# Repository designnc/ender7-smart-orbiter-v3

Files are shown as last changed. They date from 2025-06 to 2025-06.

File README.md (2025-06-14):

# Creality Ender 7 - Smart Orbiter 3 + Klipper Build

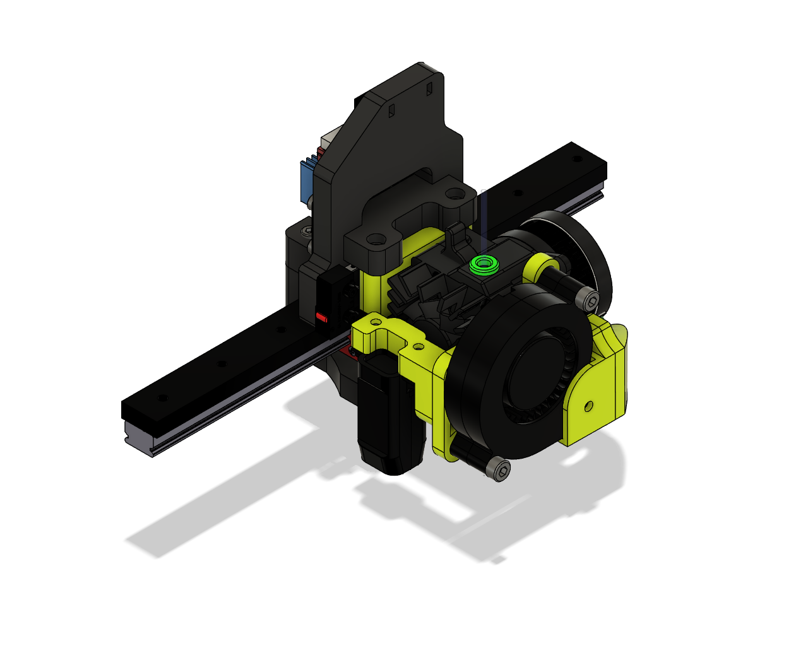
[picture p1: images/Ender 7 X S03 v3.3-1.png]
Overview Image


## Table of Contents / Tabla de Contenidos

- [Project Description / Descripción del Proyecto](#project-description--descripción-del-proyecto)
- [Important Warnings / Advertencias](#important-warnings--advertencias)
- [Repository Structure / Estructura del Repositorio](#repository-structure--estructura-del-repositorio)
- [Klipper Configuration / Configuración de Klipper](#klipper-configuration--configuración-de-klipper)
- [Mount Files / Archivos de Montaje](#mount-files--archivos-de-montaje)
  - [Assembly Notes / Notas de Ensamblaje](#assembly-notes--notas-de-ensamblaje)
- [EzMount Mod / Mod EzMount](#ezmount-mod--mod-ezmount)
- [Known Issues / Problemas Conocidos](#known-issues--problemas-conocidos)
- [Installation / Instalación](#installation--instalación)
- [Credits / Créditos](#credits--créditos)
- [License / Licencia](#license--licencia)

---

## Project Description / Descripción del Proyecto

This project documents the modification of a **Creality Ender 7** 3D printer using a **Smart Orbiter 3** direct-drive extruder, combined with **Klipper** firmware. The goal is to improve print quality, extrusion accuracy, and compatibility with flexible filaments.

Este proyecto documenta la modificación de una **Creality Ender 7** con un extrusor directo **Smart Orbiter 3**, utilizando firmware **Klipper**, con el fin de mejorar la calidad de impresión y la compatibilidad con filamentos flexibles.

🔗 Learn more / Más información: [https://www.orbiterprojects.com/so3/](https://www.orbiterprojects.com/so3/)

---

## Important Warnings / Advertencias

1. **Reduced print volume / Área de impresión reducida**:  
   From / De **250x250x300 mm** → To / A **240x240x295 mm**

2. **belt modification / Modificación de correas**:  
   You'll need to trim the belts / Se deben recortar ligeramente las correas.

3. **Y endstop relocation / Reubicación del endstop del eje Y**:  
   Must be moved forward / Debe moverse hacia adelante.  
   ✅ Adapter included / Adaptador incluido

---

## Repository Structure / Estructura del Repositorio

- `mount/3mf/`: Printable `.3mf` files / Archivos `.3mf` listos para imprimir  
- `mount/editable/`: Editable `.step` files / Archivos `.step` editables  
- `mount/Ender 7 X SO3 v.3.3/`: Main mount  
- `klipper/`: Klipper config / Configuración Klipper  
- `slicer/OrcaSlicer/`: OrcaSlicer profiles  
- `images/`: Assembly photos / Fotos del ensamblaje  
- `wiring/`: Wiring diagrams / Diagramas de conexiones  
- `SO3/SO3_EzMount_v1/`: Fan + probe mount mod

---

## Klipper Configuration / Configuración de Klipper

- `printer.cfg`: Main config  
- `SO3.cfg`: Smart Orbiter 3 config  
- `crtouch.cfg` / `microprobe.cfg`: Probes  
- `drivers_tmc2209.cfg` / `tmc5160.cfg`: Stepper drivers  
- `macros.cfg`: Useful macros

Modular configuration using `include`.

---

## Mount Files / Archivos de Montaje

Parts to mount the Smart Orbiter 3 on the Ender 7:

- `3mf/`: Ready-to-print  
- `editable/`: Editable `.step` for customization  
- Main mount: `mount/Ender 7 X SO3 v.3.3/`

### Assembly Notes / Notas de Ensamblaje

The main mount located in `mount/Ender 7 X SO3 v.3.3/` includes all components required to attach the Smart Orbiter 3 to the Ender 7.

- Uses **M3 screws** and **heat-set threaded brass inserts**
- Includes motor mount, hotend support, fan duct, and belt holder
- Exact screw lengths and quantities to be confirmed

---

El montaje principal ubicado en `mount/Ender 7 X SO3 v.3.3/` incluye todas las piezas necesarias para instalar el Smart Orbiter 3 en la Ender 7.

- Utiliza **tornillos M3** y **insertos metálicos tipo termofijado**
- Incluye soporte de motor, soporte de hotend, ducto de ventilación y tensor de correa
- Las longitudes y cantidades exactas de tornillos serán confirmadas

---

## EzMount Mod / Mod EzMount

Custom mount for the fan and probe directly on SO3:

- Located in `SO3/SO3_EzMount_v1/`
- `.3mf` files
- Previews:

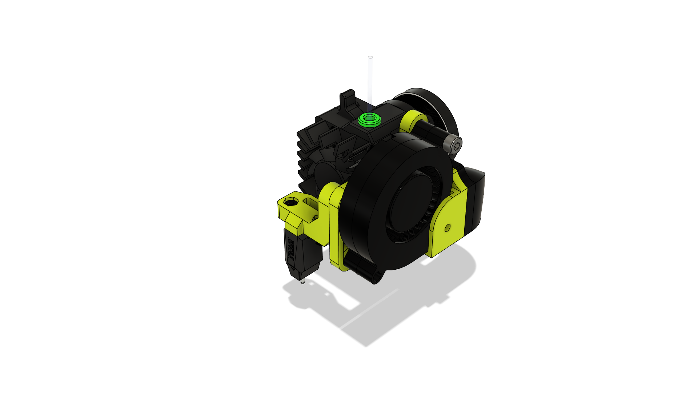
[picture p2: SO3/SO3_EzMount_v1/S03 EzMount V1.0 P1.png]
S03 EzMount P1
  
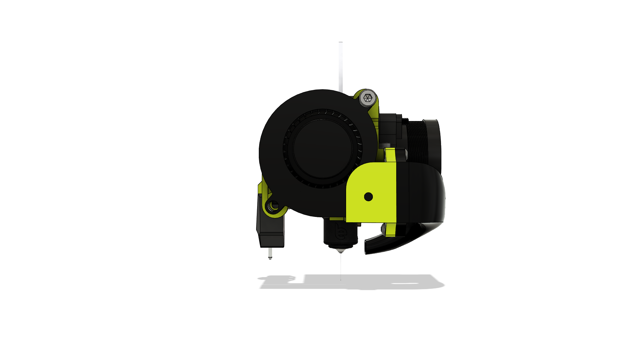
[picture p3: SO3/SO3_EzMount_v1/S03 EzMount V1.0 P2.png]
S03 EzMount P2
  
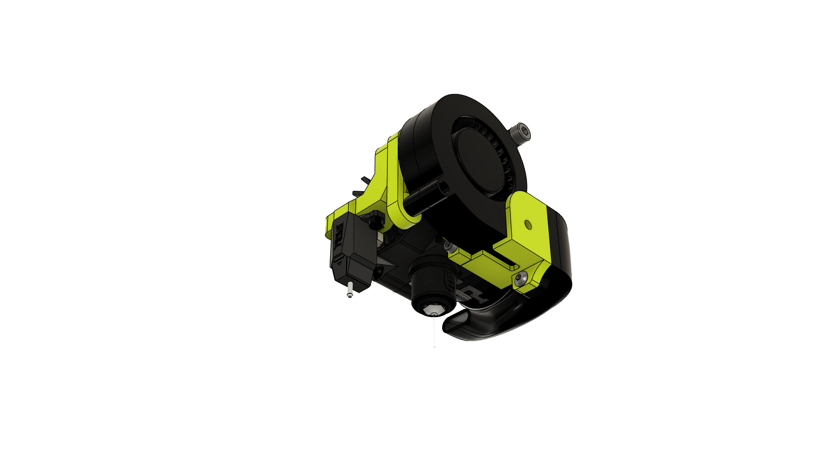
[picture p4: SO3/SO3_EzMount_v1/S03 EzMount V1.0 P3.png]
S03 EzMount P3


> This mod simplifies wiring and reduces the number of printed parts.

---

## Known Issues / Problemas Conocidos

These issues may vary depending on print speed, slicer settings, and printer condition.

---

Estos problemas pueden variar según la velocidad de impresión, el laminador y el estado de la impresora.

### 🌀 Vibrations / Vibraciones

- Some noticeable **vibrations** during fast movements or high-speed printing  
- Using the original **plastic cover** over the head may worsen this — removal is recommended

---

Durante movimientos rápidos o impresiones a alta velocidad, se pueden notar **vibraciones**.  
El uso de la **tapa protectora plástica original** puede aumentar estas vibraciones — se recomienda retirarla.

### 🔊 Fan Noise / Ruido del Ventilador

- The small **cooling fan on the SO3** can produce a **high-pitched noise** ("mosquito-like") due to its speed and size

---

El pequeño **ventilador de enfriamiento del SO3** puede generar un **ruido agudo tipo mosquito** debido a su alta velocidad y tamaño reducido.

---

## Installation / Instalación

1. Print parts from `mount/3mf/` or `SO3_EzMount_v1/`  
2. Trim Y belts and relocate endstop (adapter included)  
3. Load Klipper config files from `klipper/`  
4. Tune PID, axis offsets and travel limits  
5. Import OrcaSlicer profile from `slicer/OrcaSlicer/` *(coming soon)*

---

## Credits / Créditos

Based on: **Smart Orbiter 3** by **Dr. Róbert Lőrincz**, manufactured in collaboration with **LDO Motors**  
Mod design and adaptation for Ender 7 by **@designnc**  
Thanks to / Gracias a: Klipper + Ender 7 community

---

## License / Licencia

This project is licensed under the **Creative Commons Attribution-NonCommercial-ShareAlike 4.0 International (CC BY-NC-SA 4.0)** license.

You are free to remix, adapt, and build upon this work **non-commercially**, as long as you **credit the original author** (@designnc) and **license your new creations under identical terms**.

More info: [https://creativecommons.org/licenses/by-nc-sa/4.0/](https://creativecommons.org/licenses/by-nc-sa/4.0/)

---

Este proyecto está licenciado bajo **Creative Commons Atribución-NoComercial-CompartirIgual 4.0 Internacional (CC BY-NC-SA 4.0)**.

Puedes modificar, adaptar y crear versiones derivadas **solo para uso no comercial**, siempre que **des crédito al autor original** (@designnc) y **compartas tus nuevas versiones bajo la misma licencia**.

Más información: [https://creativecommons.org/licenses/by-nc-sa/4.0/deed.es](https://creativecommons.org/licenses/by-nc-sa/4.0/deed.es)

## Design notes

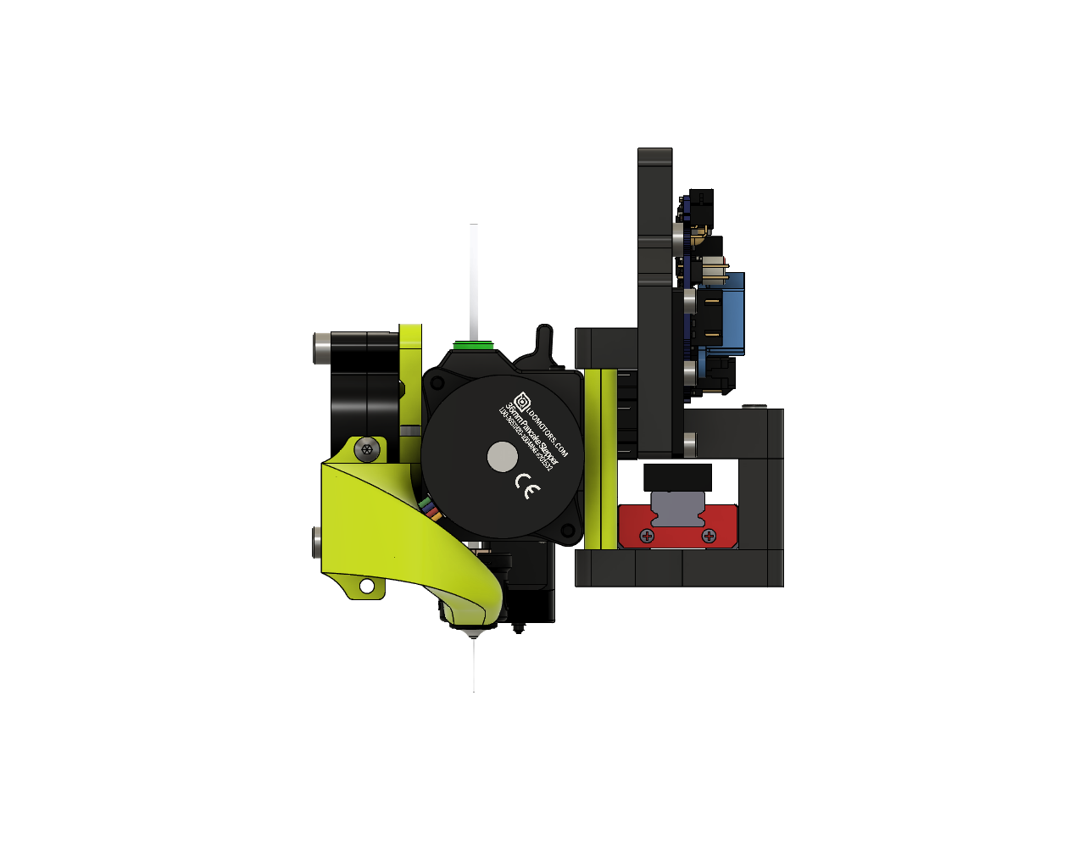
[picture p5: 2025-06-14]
images/Ender 7 X S03 v3.3-right.png

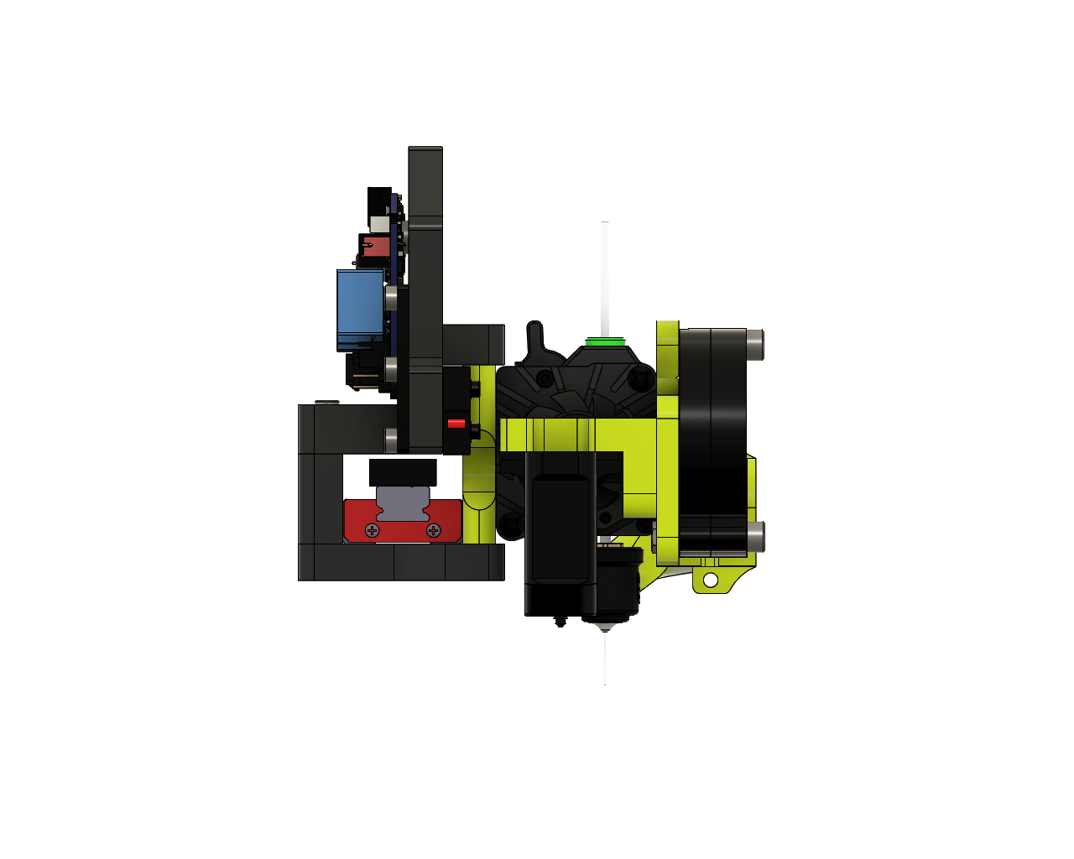
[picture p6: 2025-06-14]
images/Ender 7 X S03 v3.3-left.png

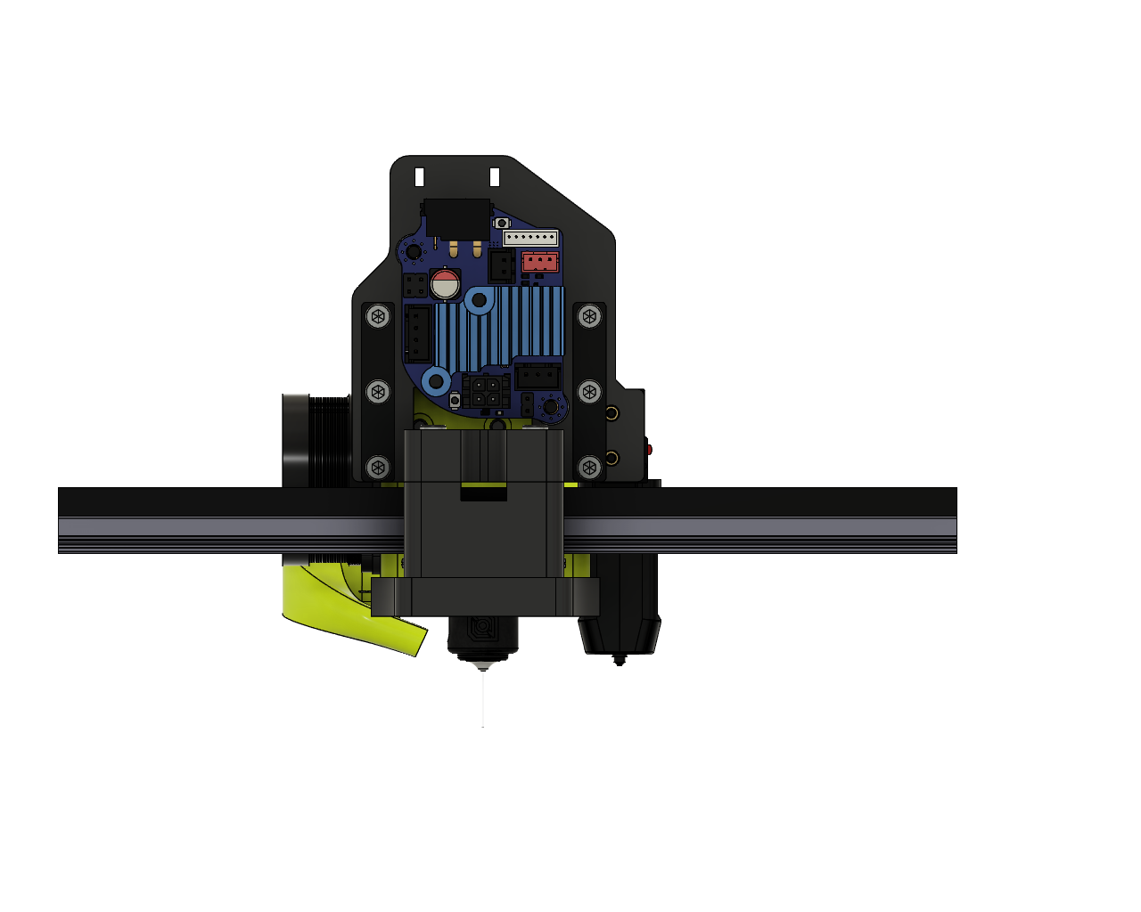
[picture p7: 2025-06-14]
images/Ender 7 X S03 v3.3-back.png

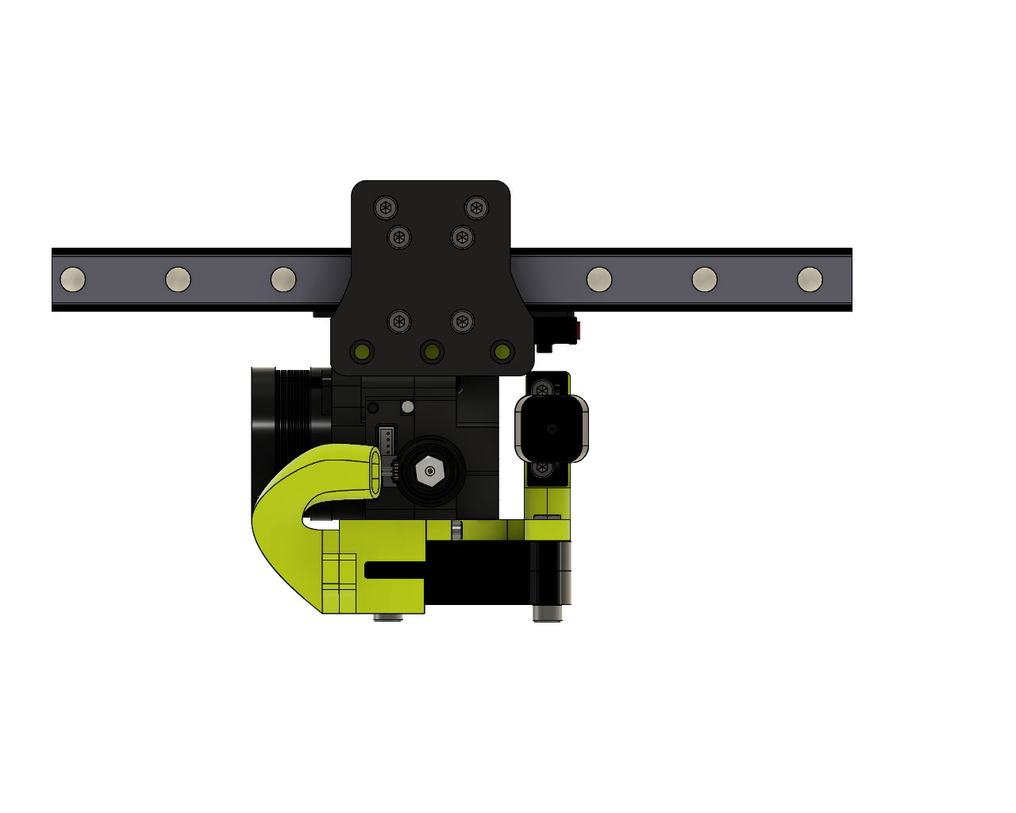
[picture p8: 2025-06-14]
images/Ender 7 X S03 v3.3-bottom.png

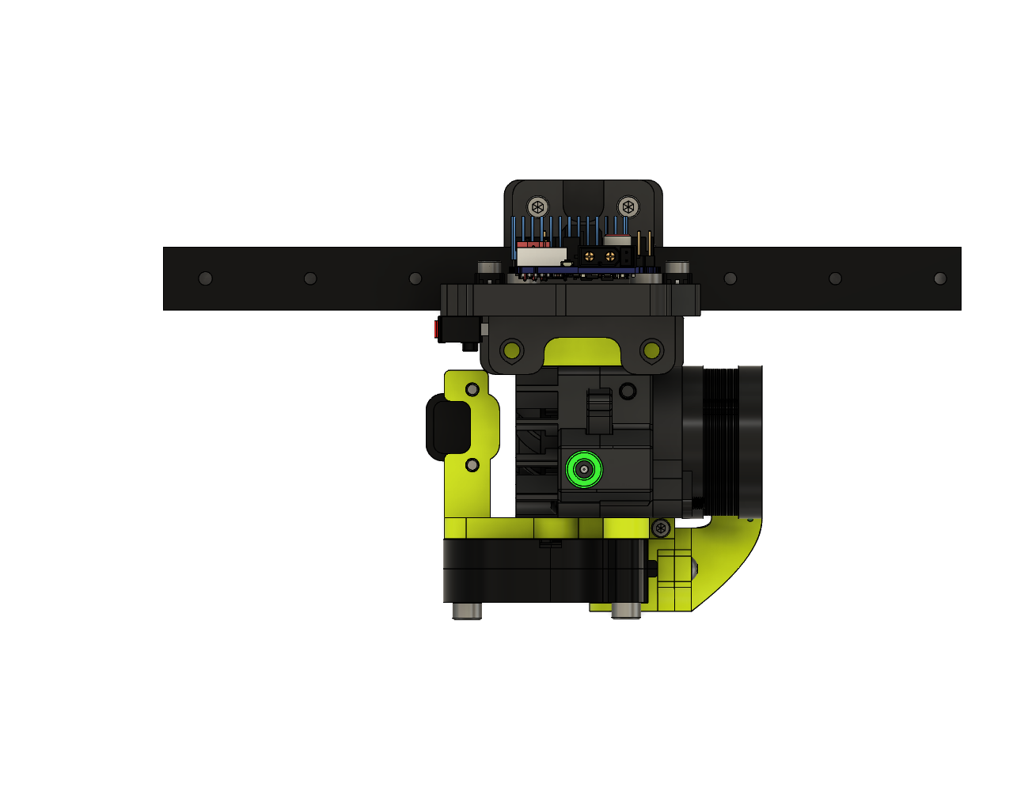
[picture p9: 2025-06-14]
images/Ender 7 X S03 v3.3-top.png

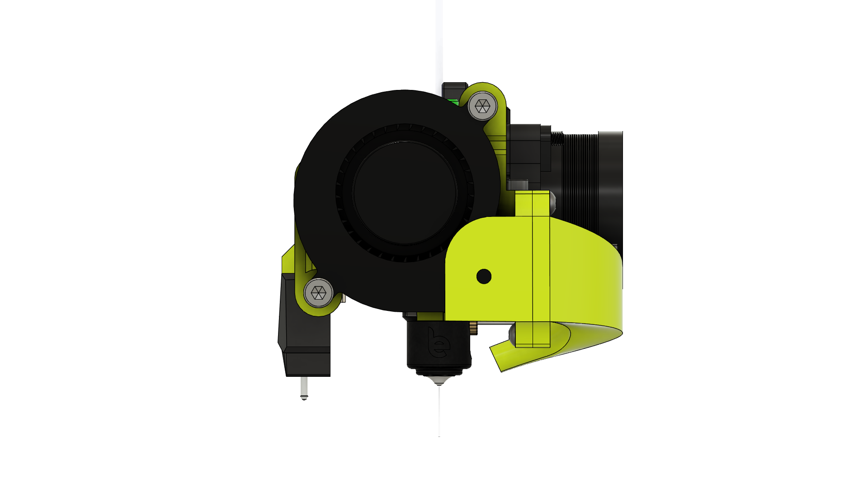
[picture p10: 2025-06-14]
SO3/SO3_EzMount_v1/SO3-v2.3 front.png

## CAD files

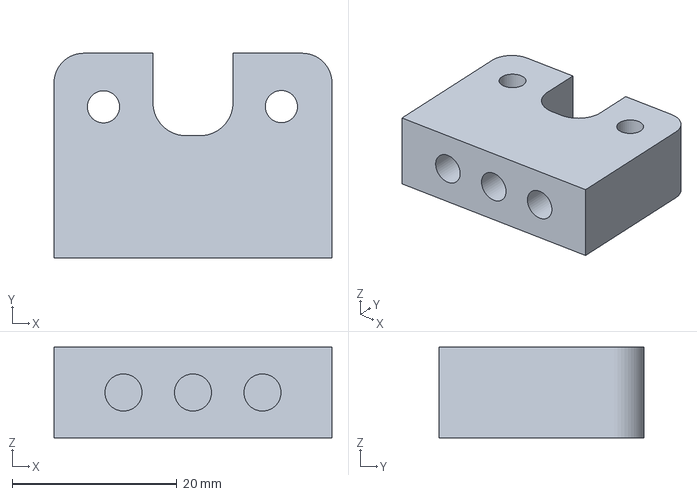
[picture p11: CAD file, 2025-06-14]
mount/Ender 7 X SO3 v.3.3/back_belt_mount.3mf
33.7 x 24.8 x 11.0 mm

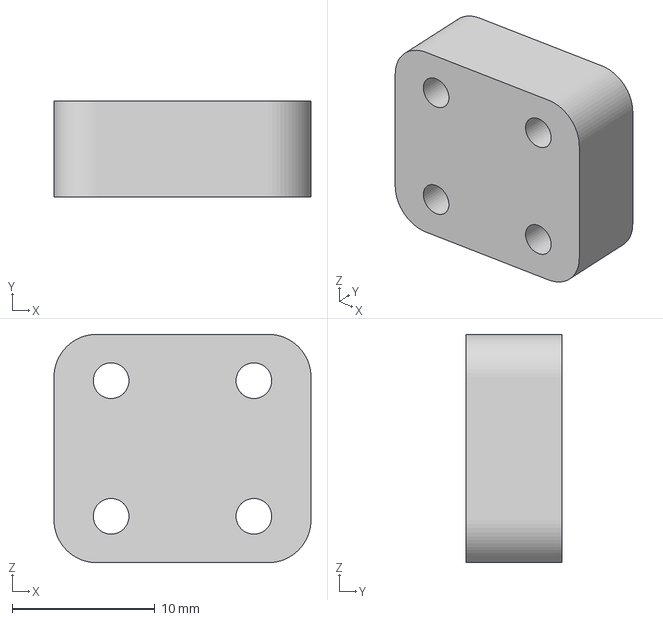
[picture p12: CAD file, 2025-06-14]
mount/Y-adapter.3mf
18.0 x 6.70 x 16.0 mm

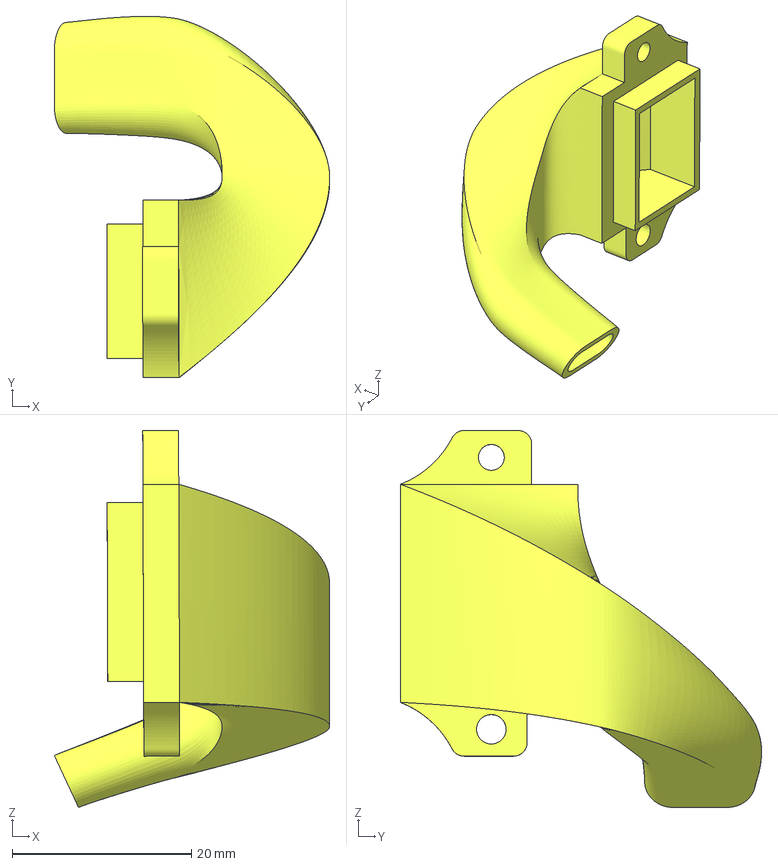
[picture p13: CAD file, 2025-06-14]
SO3/SO3_EzMount_v1/duct_4.3mf
30.7 x 40.3 x 42.1 mm

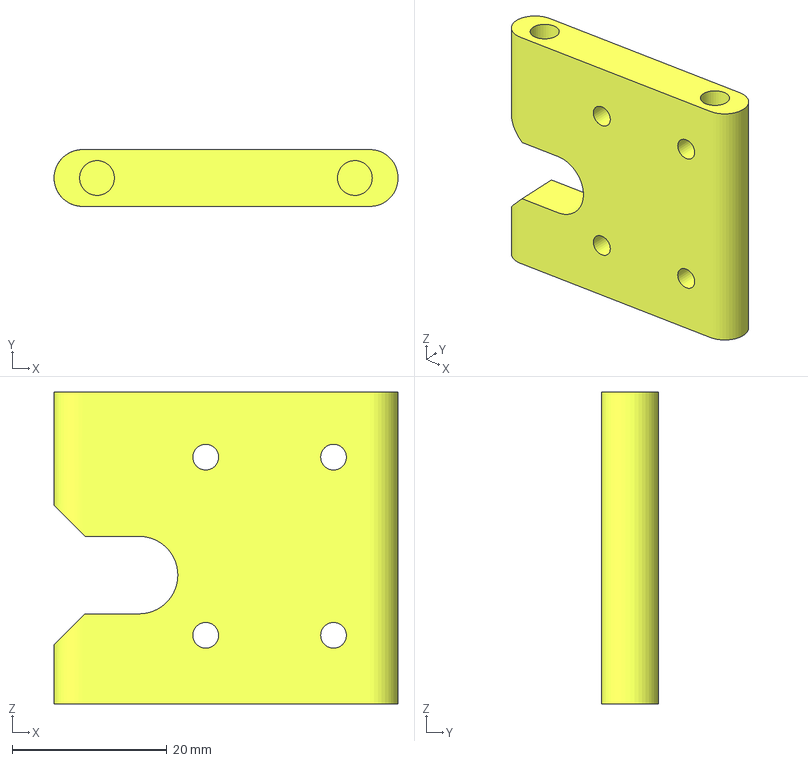
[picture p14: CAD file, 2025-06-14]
mount/Ender 7 X SO3 v.3.3/S03_mount.3mf
44.4 x 7.34 x 40.2 mm

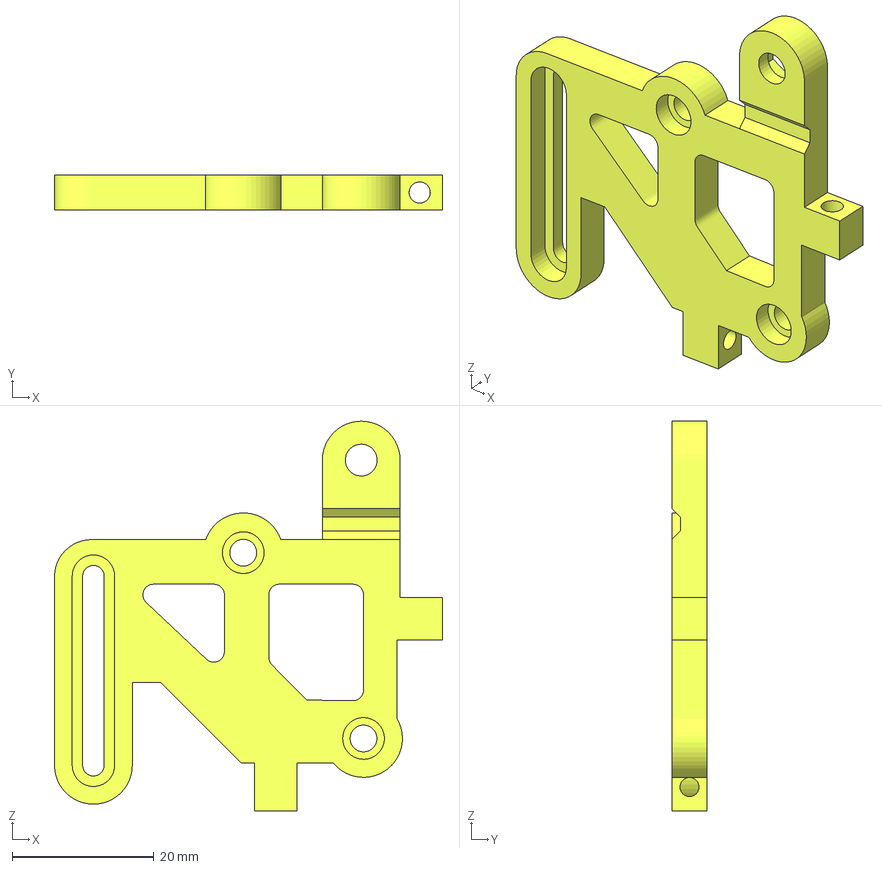
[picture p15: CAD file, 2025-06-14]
SO3/SO3_EzMount_v1/bracket_v2.1.3mf
54.8 x 5.00 x 55.1 mm

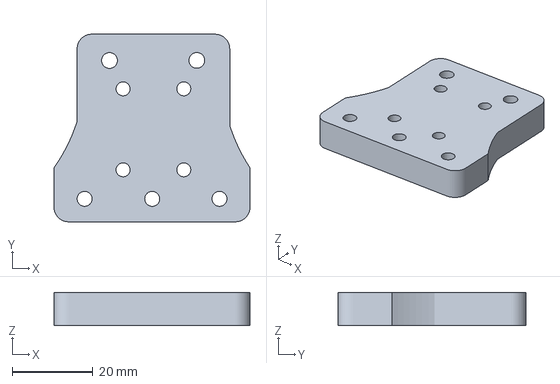
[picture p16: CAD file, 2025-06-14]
mount/Ender 7 X SO3 v.3.3/railmount.3mf
48.4 x 46.3 x 8.25 mm

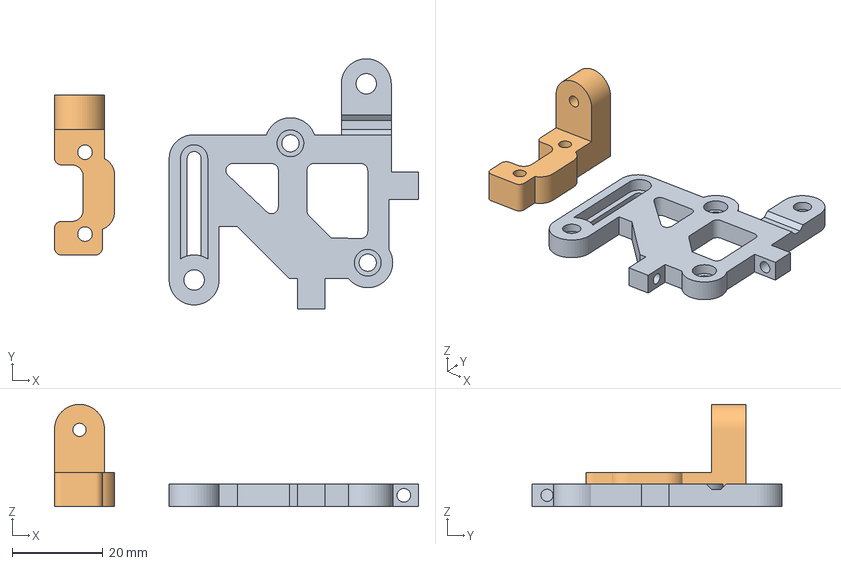
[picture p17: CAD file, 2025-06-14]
SO3/SO3_EzMount_v1/print.3mf
80.0 x 55.1 x 22.5 mm
bracket_v2
bl_cr_mount

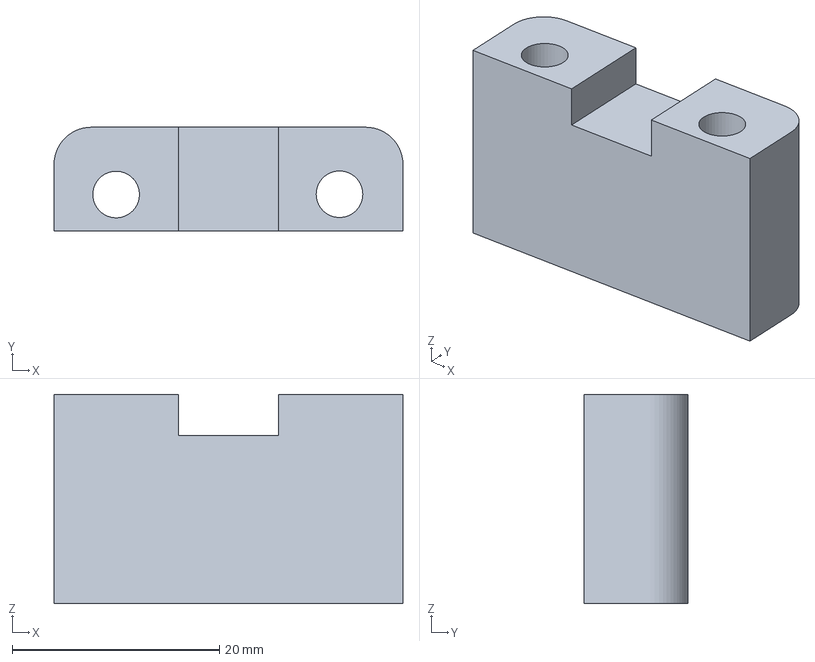
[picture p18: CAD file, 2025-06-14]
mount/Ender 7 X SO3 v.3.3/railmount_back.3mf
33.7 x 10.0 x 20.2 mm

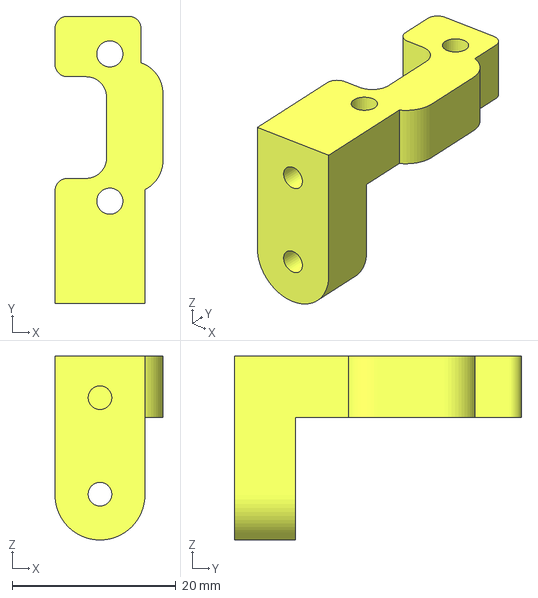
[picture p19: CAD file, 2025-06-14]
SO3/SO3_EzMount_v1/bl_cr_mount.3mf
13.2 x 35.1 x 22.5 mm

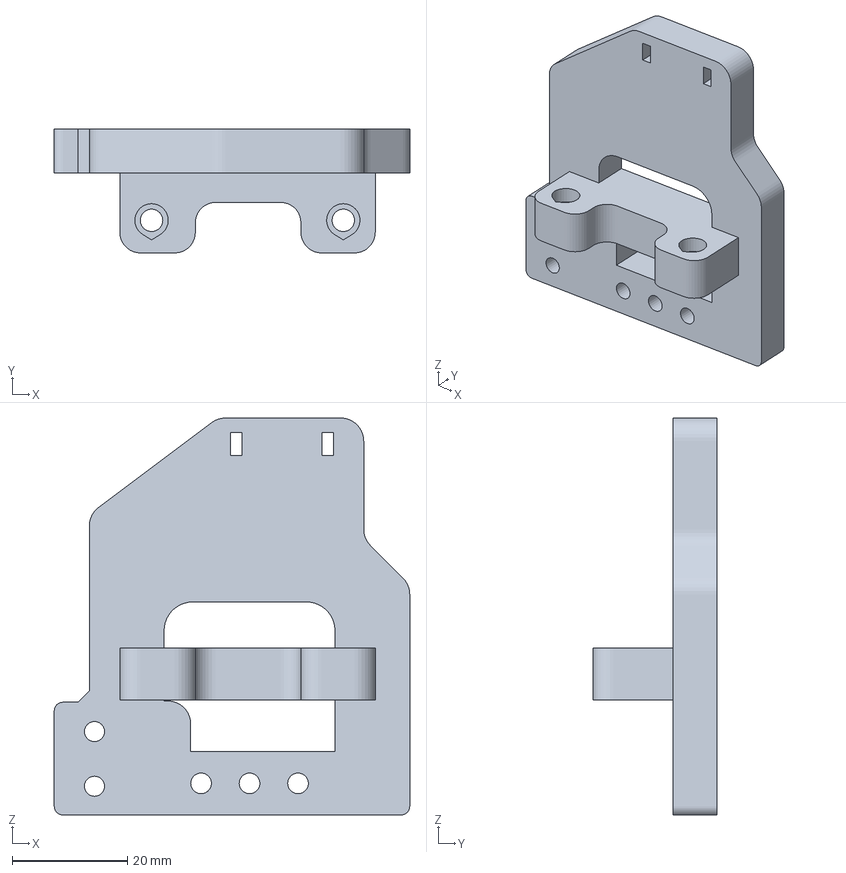
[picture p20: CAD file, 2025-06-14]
mount/Ender 7 X SO3 v.3.3/backplate.3mf
61.8 x 21.5 x 69.0 mm

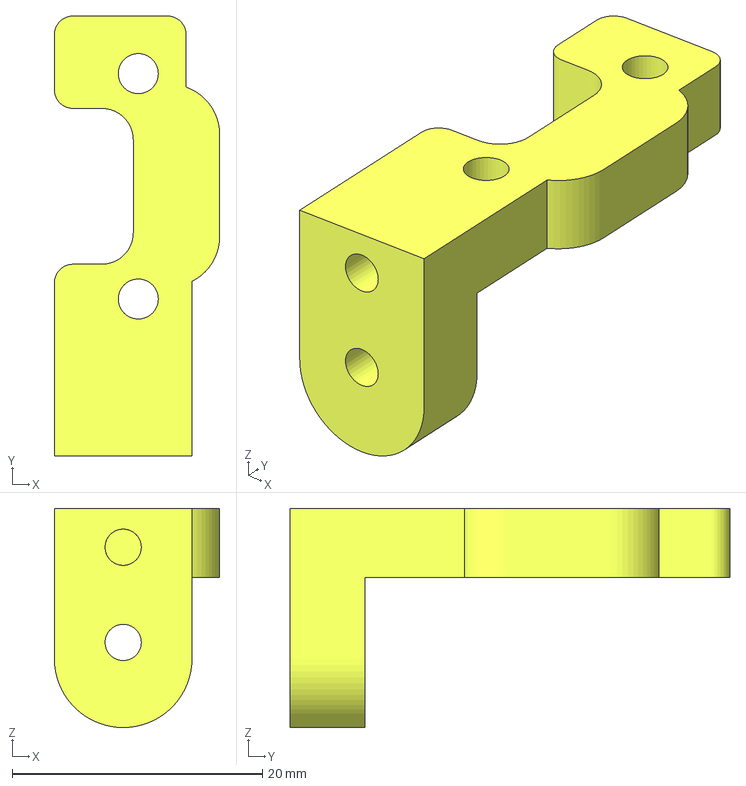
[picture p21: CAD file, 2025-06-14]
SO3/SO3_EzMount_v1/cr_mount.3mf
13.2 x 35.1 x 17.5 mm

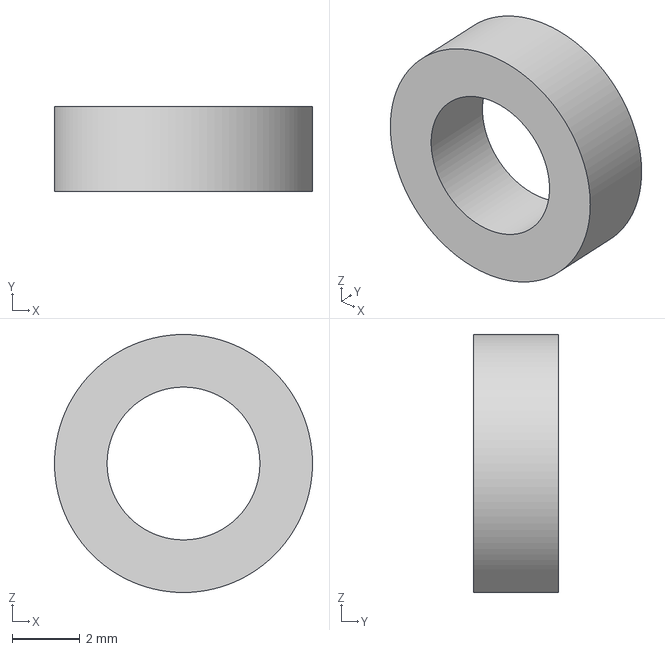
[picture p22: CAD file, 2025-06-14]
mount/Ender 7 X SO3 v.3.3/toolboard-spacer-2.3mf
7.60 x 2.50 x 7.60 mm

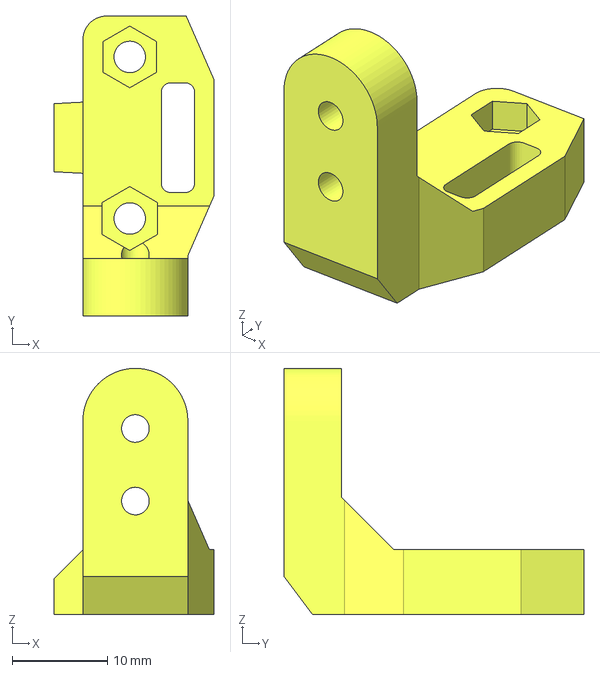
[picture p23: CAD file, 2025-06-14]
SO3/SO3_EzMount_v1/microprobe_mount.3mf
16.7 x 31.4 x 25.8 mm

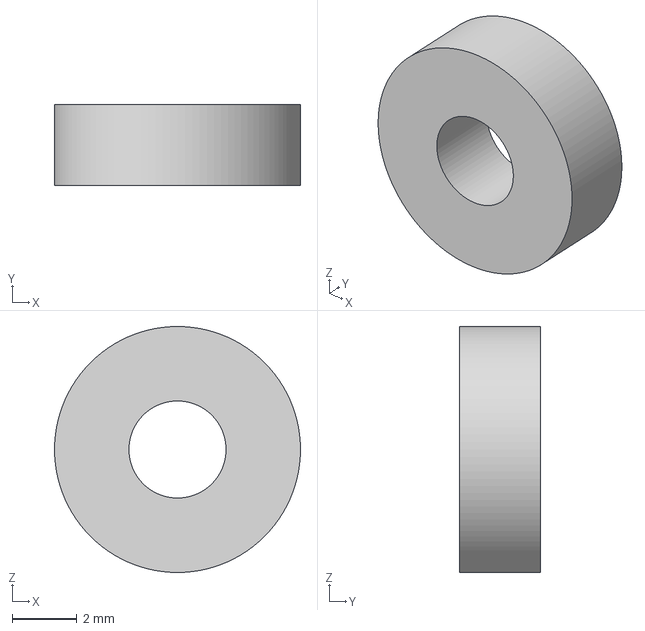
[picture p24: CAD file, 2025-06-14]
mount/Ender 7 X SO3 v.3.3/toolboard-spacer-1.3mf
7.60 x 2.50 x 7.60 mm

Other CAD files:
SO3/SO3_EzMount_v1/fan_mount.3mf
SO3/SO3_EzMount_v1/bracket_v2.3mf

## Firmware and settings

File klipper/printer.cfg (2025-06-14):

#[include mainsail.cfg]
[include macros.cfg]
[include timelapse.cfg]
[include SO3.cfg]
#[include SO3_old.cfg]
#[include PIS.cfg]

############################################################################################################################################################
# MCU and Default Machine Configuration
############################################################################################################################################################

# host MCU service is preinstalled and ready to use with:
[mcu CB1]
serial: /tmp/klipper_host_mcu

# This file contains common pin mappings for the BIGTREETECH Manta E3EZ
# To use this config, the firmware should be compiled for the
# STM32G0B1 with a "8KiB bootloader" "8 MHz crystal"
# and "USB (on PA11/PA12)" or "CAN bus (on PB12/PB13)".

# See docs/Config_Reference.md for a description of parameters.

[mcu]
serial: /dev/serial/by-id/usb-Klipper_stm32g0b1xx_54002C0002504B5735313920-if00

[mcu SO3]
serial: /dev/serial/by-id/usb-Klipper_stm32f042x6_SO3Tool-if00


############################################################################################################################################################
# Steppers  Configuration 
############################################################################################################################################################

[stepper_x]
step_pin: PA14
dir_pin: PA10
enable_pin: !PA13
microsteps: 64 #64
rotation_distance: 64 #64
endstop_pin: SO3:PB0
position_endstop: 0
position_max: 247 #255
homing_speed: 80

[stepper_y]
step_pin: PC8
dir_pin: PA15
enable_pin: !PC14
microsteps: 64 #64
rotation_distance: 64 #64
endstop_pin: ^PC4
position_endstop: 240
position_max: 240 #250
homing_speed: 80

[stepper_z]
step_pin: PD2
dir_pin: PD4
enable_pin: !PD3
microsteps: 16
rotation_distance: 8
endstop_pin: probe:z_virtual_endstop #required for BLtouch
#endstop_pin: ^PC6 #use without BLtouch
#position_endstop: 0 #use without BLtouch
position_min: -5  #required for BLtouch
position_max: 295

############################################################################################################################################################
# Drivers Configuration
############################################################################################################################################################

#[tmc2209 extruder]
#uart_pin: PD1                                #define correct pin number
#interpolate: true
#run_current: 0.85 #**
#sense_resistor: 0.11 #**
#stealthchop_threshold: 0
#driver_TBL: 0
#driver_HEND: 6
#driver_HSTRT: 7
#driver_TOFF: 4

# Driver XY
#[include drivers_tmc2209.cfg]
[include drivers_tmc5160.cfg] #only used with 5160 stepper driver

[tmc2209 stepper_z]
uart_pin: PD0
#diag_pin: PC6
run_current: 1.0 #0.9
stealthchop_threshold: 999999

############################################################################################################################################################
# Cooling Configuration 
############################################################################################################################################################

[temperature_sensor raspberry_pi]
sensor_type: temperature_host
min_temp: 10
max_temp: 100

[temperature_sensor mcu_temp]
sensor_type: temperature_mcu
min_temp: 0
max_temp: 100

#[fan]
#fan0
#pin: PA8

[controller_fan manta_e3ez]
#fan2
pin: PB14
fan_speed: 0.4
idle_timeout: 30
stepper: stepper_x, stepper_y



############################################################################################################################################################
# Printer Configuration 
############################################################################################################################################################

[printer]
kinematics: corexy
max_velocity: 500 #500
max_accel: 2500 #10000 #3600
max_accel_to_decel: 1500 #1800
max_z_velocity: 10
max_z_accel: 100
square_corner_velocity: 5.0

[heater_bed]
heater_pin: PB2 #HB
sensor_type: EPCOS 100K B57560G104F #Generic 3950
sensor_pin: PA3 #TB 
min_temp: 0
max_temp: 110
#control: pid
#pid_kp = 327.11
#pid_ki = 19.20
#pid_kd = 1393.45 


# Enable arcs support
[gcode_arcs]
resolution: 0.1

[virtual_sdcard]
path: ~/printer_data/gcodes
on_error_gcode: CANCEL_PRINT

[pause_resume]

[display_status]

#[respond]

#[output_pin PS_ON]
#pin: PA9

#[output_pin pb9_pin]
#pin: PB9

#[neopixel my_neopixel]
#pin: PC7

[board_pins]
aliases:
    # EXP1 header
    EXP1_1=PC1, EXP1_3=PC3, EXP1_5=PC0, EXP1_7=PA2, EXP1_9=<GND>,
    EXP1_2=PC2,  EXP1_4=<RST>, EXP1_6=PA0, EXP1_8=PA1, EXP1_10=<5V>

############################################################################################################################################################
#AUTO BED LEVELING / Bltouch / MESH SETTINGS / OFFSETS/
############################################################################################################################################################

#Probes
[include crtouch.cfg]
#[include microprobe.cfg]

[bltouch]

x_offset: -30 #required for BLtouch. Measure probe position from nozzle
y_offset: 13  #required for BLtouch. Measure probe position from nozzle
#z_offset: 0  #required for BLtouch
#speed: 3.0  #required for BLtouch
#pin_up_touch_mode_reports_triggered: False  #required for BLtouch

[safe_z_home]   #required for BLtouch
home_xy_position: 145, 120 #required for BLtouch
speed: 100  #required for BLtouch
z_hop: 10  #required for BLtouch
z_hop_speed: 5  #required for BLtouch

[bed_mesh]  #required for BLtouch
speed: 100  #required for BLtouch
horizontal_move_z: 5  #required for BLtouch
mesh_min: 10, 20  #required for BLtouch position of proble when x=0 y=0 #y=10 in this case
mesh_max: 210,240 #required for BLtouch
probe_count: 9,9  #required for BLtouch
fade_start: 1
fade_end: 10
fade_target: 0
algorithm: bicubic

[bed_screws]
screw1: 55, 30
screw2: 246, 30
screw3: 246, 220
screw4: 55, 220

[screws_tilt_adjust]
screw1: 55, 30     #screw coordinates need to be measure for YOUR specific printer
screw1_name: front left screw
screw2: 246, 30
screw2_name: front right screw
screw3: 246, 220
screw3_name: rear right screw
screw4: 55, 220
screw4_name: rear left screw
horizontal_move_z: 10.
speed: 50.   #speed of travel moves between screws
screw_thread: CW-M4  #measure your bed screw m3=3mm / m4=4mm / m5=5mm

#*# <---------------------- SAVE_CONFIG ---------------------->
#*# DO NOT EDIT THIS BLOCK OR BELOW. The contents are auto-generated.
#*#
#*# [bed_mesh default]
#*# version = 1
#*# points =
#*# 	  -0.455000, -0.432500, -0.390000, -0.367500, -0.357500, -0.357500, -0.335000, -0.355000, -0.357500
#*# 	  -0.315000, -0.277500, -0.242500, -0.232500, -0.230000, -0.220000, -0.215000, -0.225000, -0.222500
#*# 	  -0.247500, -0.202500, -0.180000, -0.160000, -0.157500, -0.145000, -0.152500, -0.135000, -0.120000
#*# 	  -0.175000, -0.140000, -0.117500, -0.095000, -0.080000, -0.072500, -0.057500, -0.012500, -0.045000
#*# 	  -0.100000, -0.060000, -0.030000, 0.015000, 0.002500, 0.007500, 0.012500, 0.060000, 0.015000
#*# 	  -0.027500, 0.022500, 0.087500, 0.082500, 0.117500, 0.125000, 0.110000, 0.087500, 0.082500
#*# 	  0.025000, 0.070000, 0.110000, 0.150000, 0.165000, 0.177500, 0.175000, 0.192500, 0.192500
#*# 	  0.117500, 0.172500, 0.190000, 0.222500, 0.242500, 0.260000, 0.287500, 0.280000, 0.280000
#*# 	  0.207500, 0.267500, 0.305000, 0.330000, 0.367500, 0.390000, 0.397500, 0.405000, 0.400000
#*# x_count = 9
#*# y_count = 9
#*# mesh_x_pps = 2
#*# mesh_y_pps = 2
#*# algo = bicubic
#*# tension = 0.2
#*# min_x = 10.0
#*# max_x = 210.0
#*# min_y = 20.0
#*# max_y = 240.0
#*#
#*# [extruder]
#*#
#*# [heater_bed]
#*# control = pid
#*# pid_kp = 74.855
#*# pid_ki = 1.715
#*# pid_kd = 816.851
#*#
#*# [input_shaper]
#*# shaper_type_x = 2hump_ei
#*# shaper_freq_x = 57.4
#*# shaper_type_y = 3hump_ei
#*# shaper_freq_y = 49.8
#*#
#*# [bltouch]
#*# z_offset = 2.230

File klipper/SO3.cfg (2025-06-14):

#config file version v2.2.7
#release date: 14.12.2024

#Contributors: Lorincz Robert, Tomblarom

# PAUSE, RESUME and CANCEL macros are defined at the end of this config file.
# If you prefer using your own please delete them, otherwise define parking position below.
#when using PAUSE, RESUME and CANCEL macros of this file, please comment out the #[inlcude mainsail.cfg] from you printer.cfg file.

[mcu SO3]
serial: /dev/serial/by-id/usb-Klipper_stm32f042x6_SO3Tool-if00

#SO3 Tool-board pinout definition
# PA0 - Hotend heater control
# PA1 - Hotend power sensing input
# PA2 - Hotend temperature sensor input
# PA3 - Extruder fan Tacho input
# PA4 - LIS2DW12 nCS - SPI1
# PA5 - LIS2DW12 CLK
# PA6 - LIS2DW12 SDO
# PA7 - LIS2DW12 SDI
# PA8 - Extruder PWM fan speed control
# PA9 - Hotend lit LED control signal
# PA10 - Filament unload button
# PA11 - USB Data -
# PA12 - USB Data +
# PA13 - Filament sensor
# PA14 - Part fan PWM
# PA15 - Z sensor probe input

# PB0 - X end stop
# PB1 - extruder temperature
# PB3 - Z sensor servo output
# PB4 - TMC2209 nEN
# PB5 - TMC2209 UART
# PB6 - TMC2209 DIR
# PB7 - TMC2209 STEP
# PB8 - RGB LED

#################################################################################################################
################################ CHANGE HERE MACRO CONFIGURABLES ################################################
#################################################################################################################

[gcode_macro _SENSOR_VARIABLES]         # change here macro configurables, enable disable functions!*************************
variable_filament_load_temp     :230    # temperature to heat up hotend for filament loading, default is 235
variable_filament_unload_temp   :185    # temperature to heat up hotend for filament un-loading, default is 185
variable_filament_load_min_temp :190    # minimum hotend set temperature allowed in filament load macro, default is 190
variable_nozzle_purge_length    :100    # filament extrude amount during load sequenc, hotend purge from old filament, default is 100
variable_nozzle_purge_speed     :300    # filament extrude speed in mm/min adjust this value lower if flow is too high and extruder skips during loading, default is 300
variable_temp_restore           :True   # [True] restore previous temperature after filament change
variable_disable_autoload       :False  # disable filament autoload feature by setting this variable True
variable_disable_runout         :False  # disable runout by setting this variable True
variable_disable_autounload     :False  # disable auto unload filament by setting this variable to True
variable_pause_on_unload_button :True   # pauses the printer if the unload button is pressed during printing
variable_disable_runout_unload  :True   # disable auto filament unload after runout detection
variable_enable_beep            :False  # uses M300 sound feature, set it True to enable
variable_park_position_x        :128    # edit your X parking position here for pause macro trigerred by runout
variable_park_position_y        :50     # edit your Y parking position here for pause macro trigerred by runout
variable_park_lift_z            :30     # edit your Z lift amount for parking position here, default is 10
variable_park_retraction        :1      # edit your retraction amount for parking, default is 1
variable_pause_timeout          :600
gcode:

[force_move]
enable_force_move: True

[respond]
default_type: echo

###########################################################################################
###################### Onboard accelerometer and resonance tester config ##################
###########################################################################################

[lis2dw]
cs_pin: SO3:PA4
spi_bus: spi1
axes_map: y, z, x

[resonance_tester]
accel_chip: lis2dw
probe_points: 140,120,30  # edit XYZ head position for testing
min_freq: 10
max_freq: 200

##################################################################
########################## EXTRUDER ##############################
##################################################################
[extruder]
step_pin: SO3:PB7
dir_pin: SO3:PB6
enable_pin: !SO3:PB4
microsteps: 32
full_steps_per_rotation: 200
#rotation_distance = <full_steps_per_rotation> * <microsteps> / <steps_per_mm>
rotation_distance: 4.69
nozzle_diameter: 0.400
filament_diameter: 1.750
max_extrude_only_distance: 2500
max_extrude_only_velocity: 120
max_extrude_only_accel: 3000
#_______________________ HEATER NOZZLE ____________________________
heater_pin: SO3:PA0
sensor_pin: SO3:PA2
#_________________________NOZZLE TEMP _____________________________
sensor_type: ATC Semitec 104NT-4-R025H42G  
pullup_resistor: 4700
min_temp: 0
max_temp: 300
pressure_advance: 0.015
pressure_advance_smooth_time: 0.03
min_extrude_temp: 170
smooth_time: 0.5
max_extrude_cross_section:10
max_power: 0.995
pwm_cycle_time: 0.01
control = pid
pid_Kp=24.859 
pid_Ki=2.072 
pid_Kd=74.578

[tmc2209 extruder] 
uart_pin: SO3:PB5
interpolate: true
run_current: 0.8
sense_resistor: 0.11
stealthchop_threshold: 0

[heater_fan extruder_Fan]
pin: !SO3:PA8
tachometer_pin: SO3:PA3
tachometer_ppr: 2
tachometer_poll_interval: 0.0005
heater: extruder
cycle_time: 0.0001 #10KHz PWM frecvency, do not change this!
heater_temp: 85
fan_speed: 0.65 # increase in case experiencing clogging during printing.
hardware_pwm: false
shutdown_speed: 0.0
max_power: 1.0

[firmware_retraction]
retract_length: 1.0
retract_speed: 100
unretract_extra_length: 0.0
unretract_speed: 80

[fan]
pin: SO3:PA14
max_power: 0.995
shutdown_speed: 0.0
cycle_time: 0.01
kick_start_time: 0.2
hardware_pwm: False

#################################################################################################################################
########################################### SO3 Features Configuration ##########################################################
#################################################################################################################################

[output_pin hot_lit]
pin: SO3:PA9
pwm: False
value: 1

[neopixel SO3RGB]
pin: SO3:PB8
chain_count: 1
color_order: GRB
initial_RED: 0.0
initial_GREEN: 1.0
initial_BLUE: 0.0

[thermistor SO3Thermistor]
temperature1: 25
resistance1: 100000
beta: 3950

[temperature_sensor SO3]
sensor_type: SO3Thermistor
sensor_pin: SO3:PB1
pullup_resistor: 4700
min_temp: 0
max_temp: 85

## STM32 MCU temp
[temperature_sensor SO3_MCU]
sensor_type: temperature_mcu
sensor_mcu: SO3

#################################################################################################################################
############################################## Runout and autoload macros #######################################################
#################################################################################################################################

#################################################################################################################################
####################################### DO NOT CHANGE ANYTHING BELOW THIS LINE!!! ###############################################
#################################################################################################################################
####################################### UNLESS YOU KNOW WHAT YOU ARE DOING OR YOU ARE BORED AND NEED TO DO SOMETHING OR YOU ARE ALONE AND NEED SOMETHING TO MESS UP YOUR LIFE OR YOU CAN DO IT BETTER THAN ME OR YOU ARE A REAL SMARTASS OR JUST BECAUSE YOU CAN OR YOU RUN OUT OF BEAR OR HAS NOTHING BETTER TO DO OR ANY UNREASONABLE REASON
#################################################################################################################################


#*****************************initial RGN LED set at printer start****************************************************************
[delayed_gcode startup_RGB_SET]
initial_duration: 2
gcode:    
  {% if printer["filament_switch_sensor SO3Sensor"].filament_detected==true %}
      SET_LED LED=SO3RGB RED=0.0 GREEN=1.0 BLUE=0.0
  {% else %}
      SET_LED LED=SO3RGB RED=1.0 GREEN=0.0 BLUE=0.0
  {% endif %}   


#***********************************filament swicth definition***********************************************************
[filament_switch_sensor SO3Sensor]
switch_pin: SO3:PA13
pause_on_runout: False # do not change to true, printer is paused in the next sections
runout_gcode: UPDATE_DELAYED_GCODE ID=runout_filter DURATION=0.5 # duration defines the filter time for runout detection
insert_gcode: filament_load_init
event_delay: 1.0
pause_delay: 0.1


#////////////////////////////////////////Filament Unload macros/////////////////////////////////////////////////

[gcode_button filament_unload]
pin: !SO3:PA10
release_gcode:  # filament unload procedure   
  SET_LED LED=SO3RGB RED=0.0 GREEN=0.5 BLUE=0.5
  filament_unload_init
press_gcode: # do not add any macro call here
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

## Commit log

2025-06-14 y spacer
    [y_spacer.3mf]
2025-06-14 y update
    [Y-adapter.3mf]
